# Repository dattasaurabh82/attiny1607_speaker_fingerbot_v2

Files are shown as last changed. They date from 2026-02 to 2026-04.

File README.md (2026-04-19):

# Speaker Watchdog V2 - ATtiny1607

> [!Note]
> [attiny1607_speaker_fingerbot_v1](https://github.com/dattasaurabh82/attiny1607_speaker_fingerbot)

## Overview

Monitors speaker power LED via LDR + comparator.
When LED goes OFF → wake from sleep → servo presses Fingerbot → wait for boot → sleep.

## Hardware

- PC2 (pin 19): Trigger input (comparator OUT + manual button, shared via R8 10K)
- PA5 (pin 6): Servo PWM (TCA0 WO5)
- PA6 (pin 7): Servo power gate (SI2301 P-FET control) ← **V2**
- PB2 (pin 14): TX (debug serial)
- PB3 (pin 15): RX (via JP2 jumper) ← **V2**

### Circuit info

| LDR based comparator | Microcontroller | Board Top (Combined) | Board Bottom (Combined)| 3D Render of PCB |
| --- | --- | --- | --- | --- |
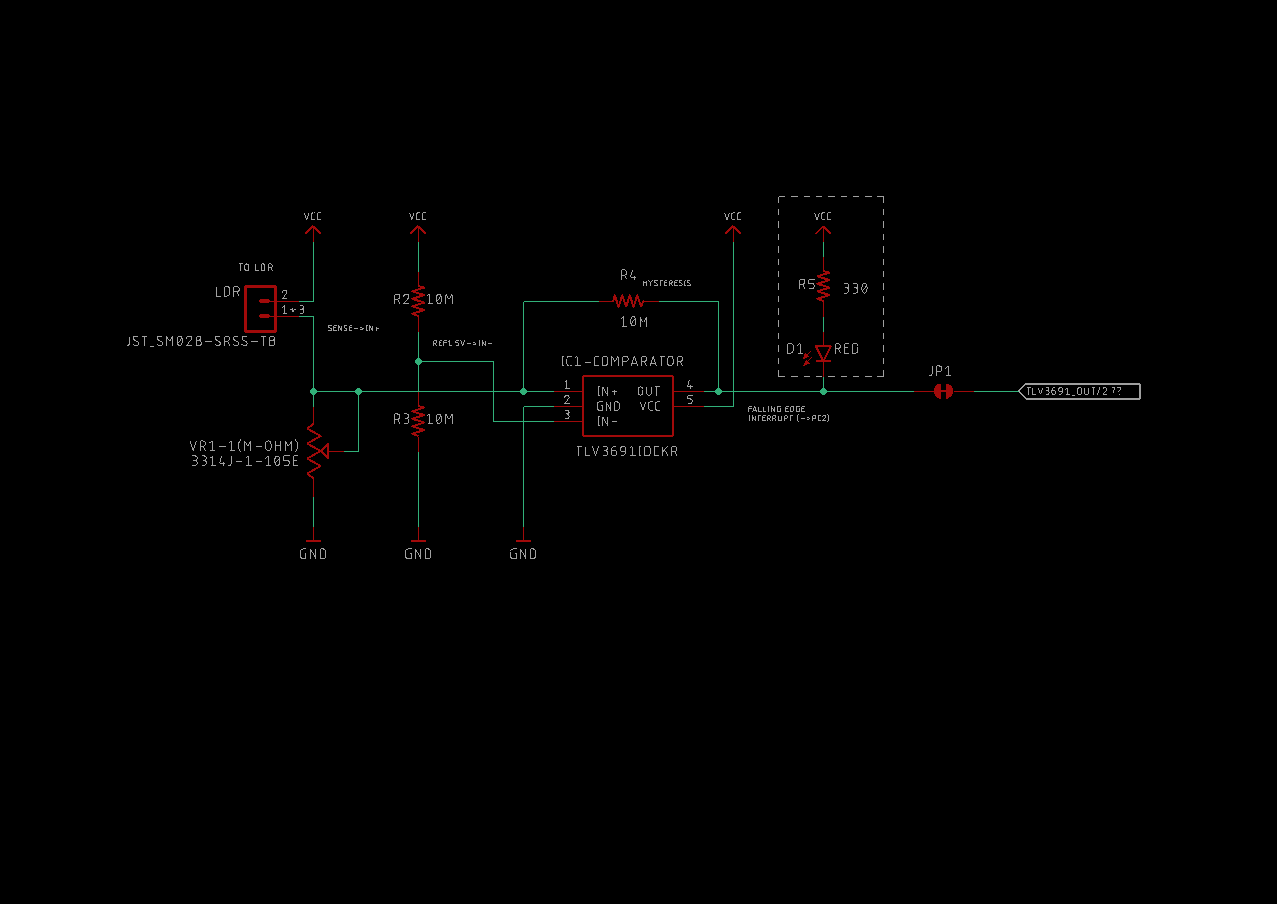
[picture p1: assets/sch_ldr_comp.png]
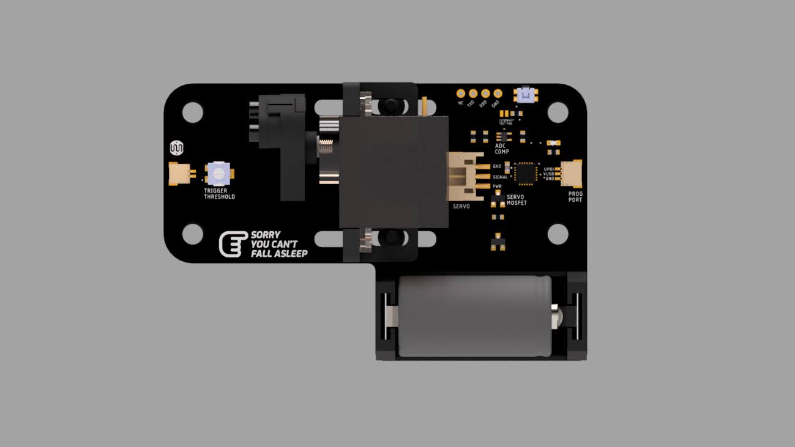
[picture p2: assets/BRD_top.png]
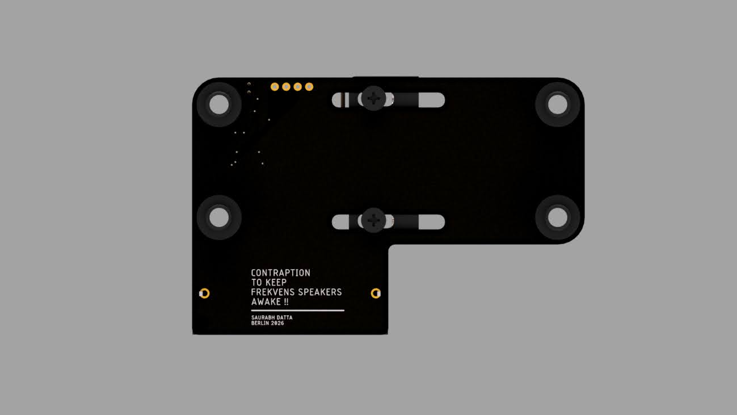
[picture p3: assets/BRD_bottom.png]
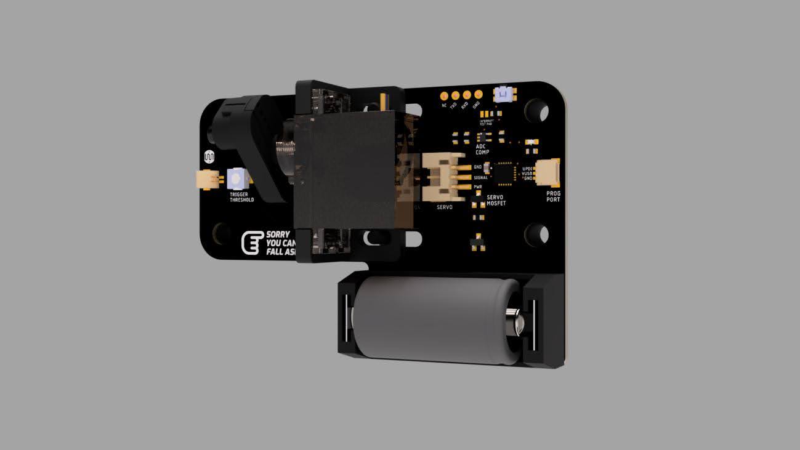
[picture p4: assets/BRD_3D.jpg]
|  |  |  |  |  |

> [!Note]
[SCHEMATIC](HW/schematic.pdf) (V-2.0)   

### What changed from V1, in V2?
> Added SI2301 P-FET to control servo power, reducing sleep current from ~2.5mA to ~300µA. Battery life improved from ~25 days to **~6 months**!

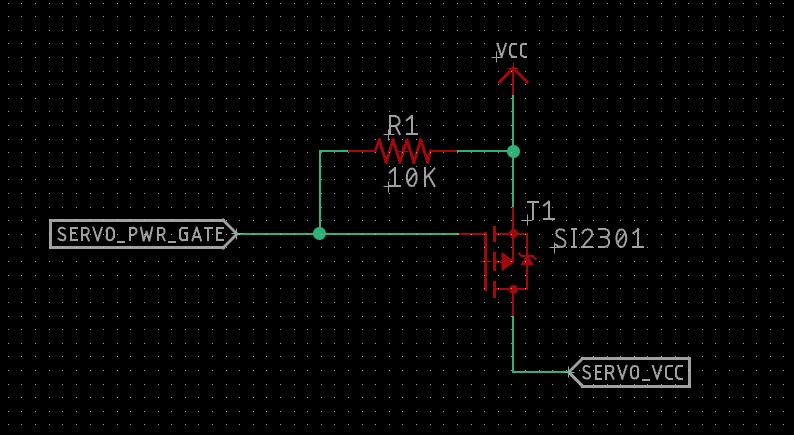
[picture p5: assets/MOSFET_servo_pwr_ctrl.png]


| MCU PA6 | Gate | Vgs | FET State | Servo |
|---|---|-----|---|---|
| HIGH (or floating) | VCC | 0V | OFF | Unpowered |
| LOW | GND | -3V | ON | Powered |

---

### Assembly (view)

<!-- ![alt text](assets/PXL_20260327_125351246.jpg) -->

<p align="center">
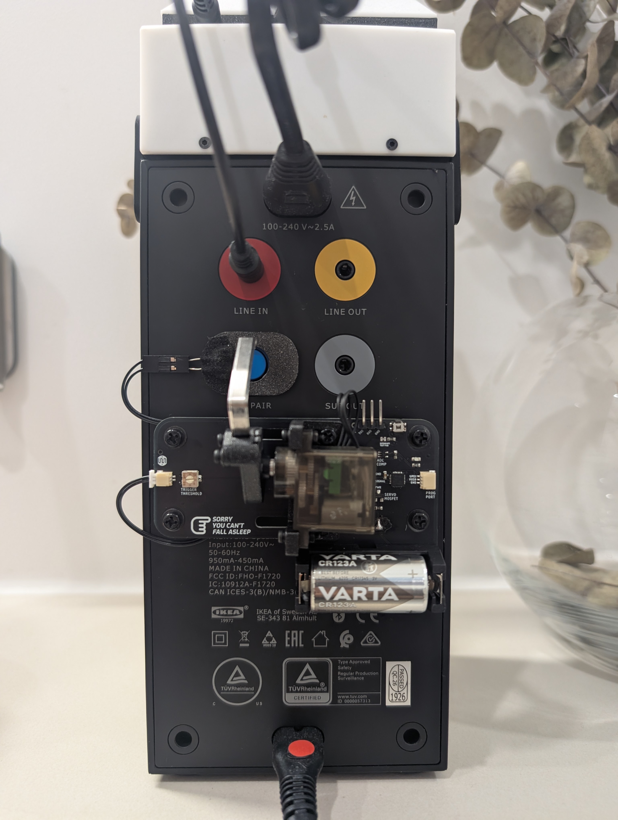
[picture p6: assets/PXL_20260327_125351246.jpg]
  
</p>

| Board bottom view | Board top view | Side view | Angled view |
| --- | --- | --- | --- |
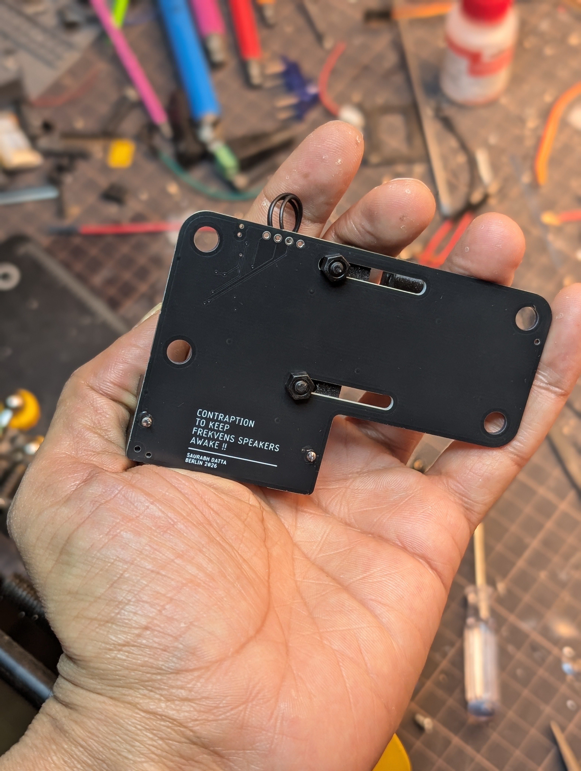
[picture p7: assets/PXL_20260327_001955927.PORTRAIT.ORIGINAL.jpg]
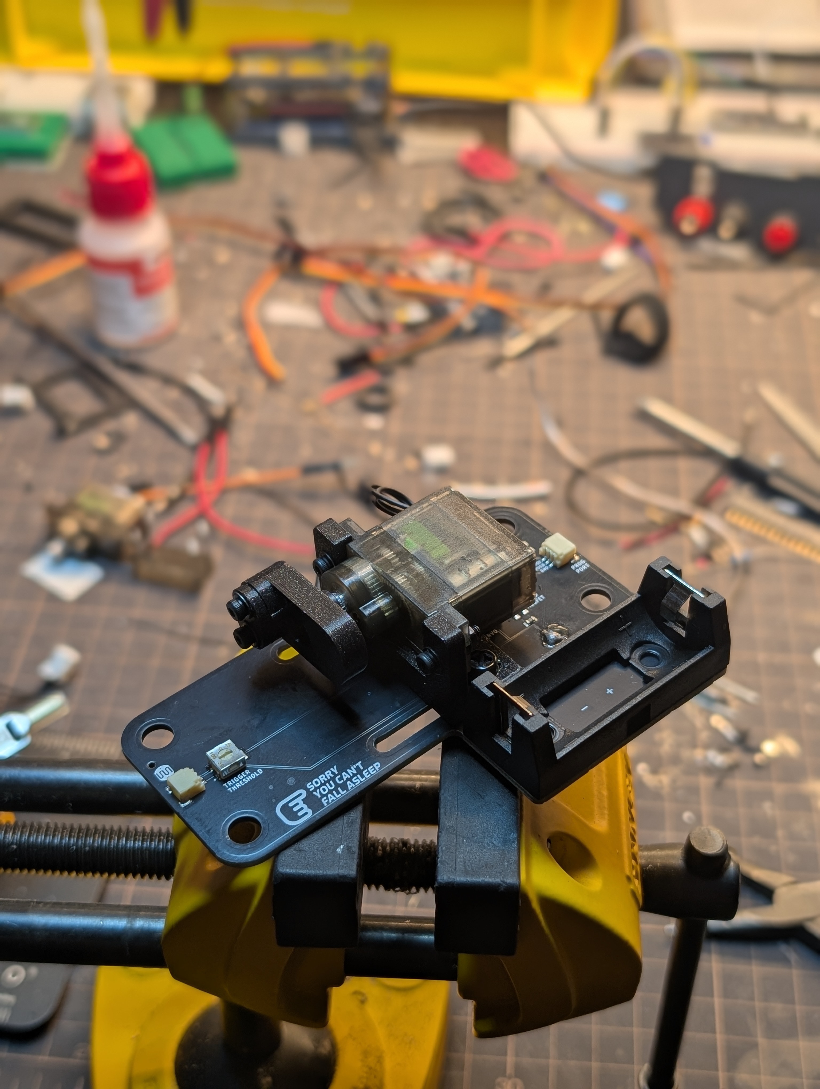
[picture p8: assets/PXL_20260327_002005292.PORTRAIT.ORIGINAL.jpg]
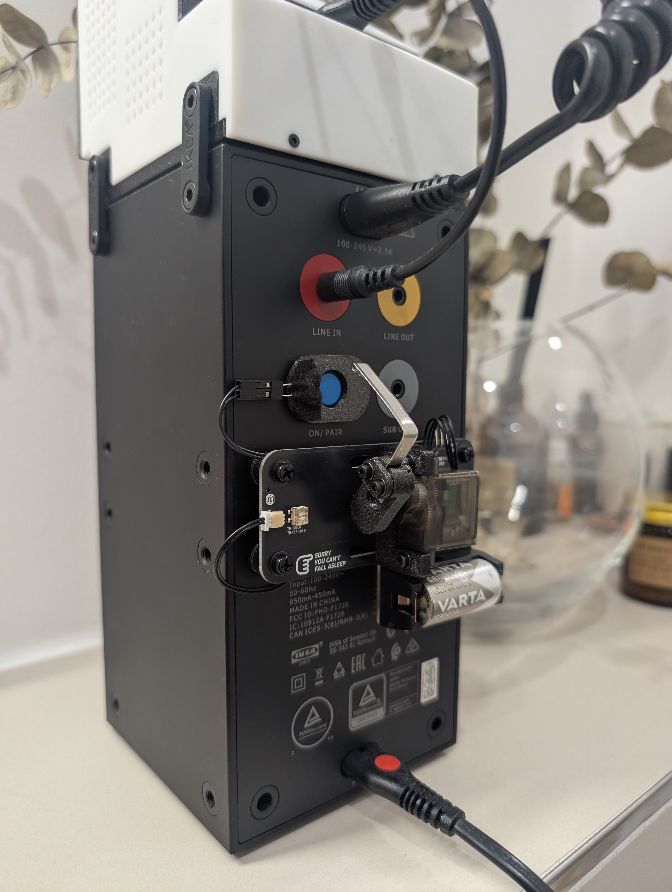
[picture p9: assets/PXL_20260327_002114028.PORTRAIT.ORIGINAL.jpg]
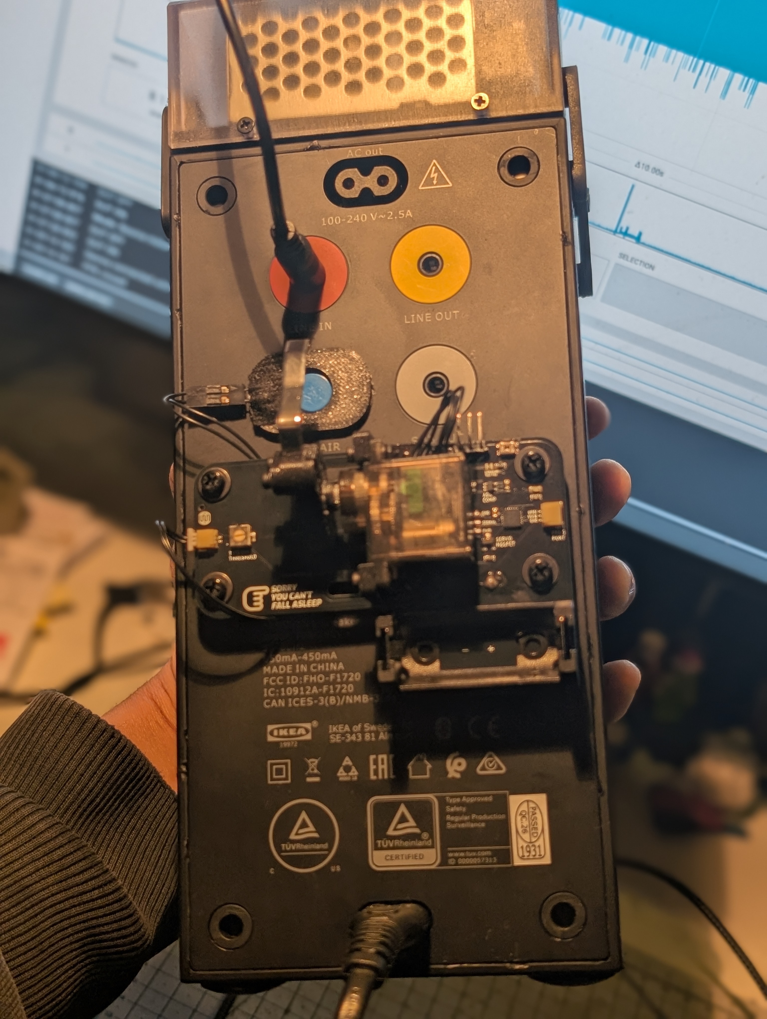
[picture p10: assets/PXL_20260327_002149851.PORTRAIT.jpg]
|  |  |  |  |

--- 

## Dependencies

- megaTinyCore: https://github.com/SpenceKonde/megaTinyCore
- Servo library: `#include <Servo_megaTinyCore.h>` (NOT `<Servo.h>`) Reason: [As Described here](https://github.com/SpenceKonde/megaTinyCore?tab=readme-ov-file#servo)

---

## Dev Setup

- IDE: Arduino IDE 2.3.8
- UPDI programmer: Could your [homebrewed one](https://github.com/SpenceKonde/AVR-Guidance/blob/master/UPDI/jtag2updi.md), but I used and followed instructions [from this one](https://learn.adafruit.com/adafruit-updi-friend?view=all)

### Compile and Upload settings:

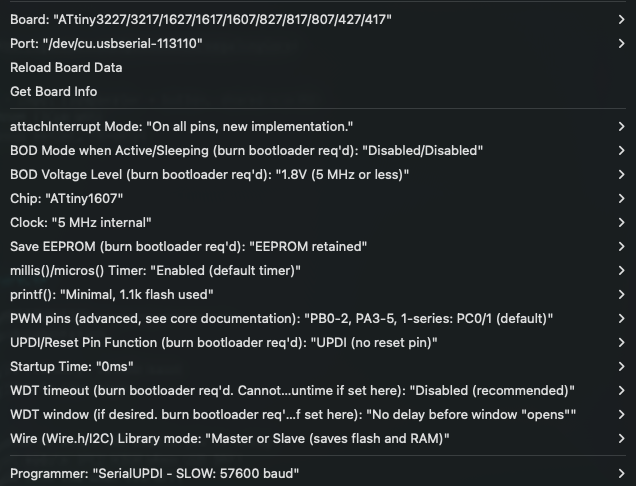
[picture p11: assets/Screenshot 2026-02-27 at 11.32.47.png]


---

## Flow

### SETUP (runs once at boot)
```
┌───────────────────────────────────────────────────────────────────┐
│  SETUP (V2)                                                       │
│  ──────────                                                       │
│  1. disableSerialPins()            // TX/RX driven LOW            │
│  2. disableUnusedPins()            // PA6 NOT included (active)   │
│  2b. disableTWI()                  // PB0/PB1 OUTPUT LOW          │
│  3. disablePeripherals()           // ADC, SPI off                │
│  4. setupTriggerPin()              // PC2 edge interrupt          │
│                                                                   │
│  5. servoPowerOn()                 // PA6=LOW → FET ON            │
│  6. delay(SERVO_STABILIZE_MS)      // Let servo settle (20ms)     │
│  7. servo.attach(PA5)                                             │
│  8. servo.write(SERVO_REST)                                       │
│  9. delay(SERVO_INIT_MS)           // Servo settles               │
│ 10. servo.detach()                                                │
│ 11. pinMode(SERVO_PIN, INPUT_PULLUP)                              │
│ 12. servoPowerOff()                // PA6=HIGH → FET OFF          │
│                                                                   │
│ 13. sei()                          // Enable global interrupts    │
│ 14. set_sleep_mode(PWR_DOWN)                                      │
│ 15. sleep_enable()                                                │
└──────────────────────────────┬────────────────────────────────────┘
                               │
                               ▼
                          ENTER LOOP
                    (servo unpowered, ~300µA sleep)
```

### MAIN LOOP
```
┌─────────────────────────────────────────────────────────────────┐
│  LOOP START                                                     │
│  ──────────                                                     │
│  - Clear pending flags                                          │
│  - sleep_cpu()                                                  │
│  - ... MCU draws ~300µA (servo is OFF via FET) ...              │
└──────────────────────────────┬──────────────────────────────────┘
                               │
               Speaker turns OFF (LED OFF)
               OR manual button pressed
               → Edge on PC2 triggers ISR
                               │
                               ▼
┌─────────────────────────────────────────────────────────────────┐
│  ISR(PORTC_PORT_vect)                                           │
│  ────────────────────                                           │
│  - flags = VPORTC.INTFLAGS                                      │
│  - PORTC.INTFLAGS = flags                                       │
│  - triggered = 1                                                │
└──────────────────────────────┬──────────────────────────────────┘
                               │
                               ▼
┌─────────────────────────────────────────────────────────────────┐
│  1. WAKE + DEBOUNCE                                             │
│     - triggered = 0                                             │
│     - [DEBUG: Serial.begin()]                                   │
│     - delay(DEBOUNCE_MS)                                        │
│     - isValidTrigger() check                                    │
│     - If FALSE → return (skip to sleep)                         │
└──────────────────────────────┬──────────────────────────────────┘
                               │
                               ▼
┌─────────────────────────────────────────────────────────────────┐
│  2. DISABLE INTERRUPT                                           │
│     - disableTriggerInterrupt()                                 │
│     - PC2 edges now ignored (prevents LED dance re-trigger)     │
└──────────────────────────────┬──────────────────────────────────┘
                               │
                               ▼
┌─────────────────────────────────────────────────────────────────┐
│  3. AWAIT BEFORE PRESS                                          │
│     - delay(SERVO_PRESS_AWAIT)    // 2000ms                     │
│     - Speaker needs time after power-off before restart works   │
└──────────────────────────────┬──────────────────────────────────┘
                               │
                               ▼
┌─────────────────────────────────────────────────────────────────┐
│  4. SERVO PRESS (V2 - with power control)                       │
│     a. servoPowerOn()             // PA6=LOW → FET ON           │
│     b. delay(SERVO_STABILIZE_MS)  // Let servo power stabilize  │
│     c. servo.attach(SERVO_PIN)                                  │
│     d. servo.write(SERVO_PRESS)   // Press position (76°)       │
│     e. delay(PRESS_HOLD_MS)       // Hold 1600ms                │
│     f. servo.write(SERVO_REST)    // Release (30°)              │
│     g. delay(PRESS_SETTLE_MS)     // Settle 1000ms              │
│     h. servo.detach()                                           │
│     i. pinMode(SERVO_PIN, INPUT_PULLUP)                         │
│     j. servoPowerOff()            // PA6=HIGH → FET OFF         │
└──────────────────────────────┬──────────────────────────────────┘
                               │
                               ▼
┌─────────────────────────────────────────────────────────────────┐
│  5. BOOT WAIT                                                   │
│     - delay(BOOT_WAIT_MS)         // 8000ms                     │
│     - Speaker boots, LED dances, interrupt disabled             │
│     - Servo already OFF (power cut by FET)                      │
└──────────────────────────────┬──────────────────────────────────┘
                               │
                               ▼
┌─────────────────────────────────────────────────────────────────┐
│  6. RE-ENABLE + CLEANUP + SLEEP                                 │
│     - enableTriggerInterrupt()                                  │
│     - clearTriggerFlags()                                       │
│     - [DEBUG: Serial cleanup]                                   │
│     - sleep_cpu()                                               │
│     - ... Back to ~300µA sleep (servo unpowered) ...            │
└─────────────────────────────────────────────────────────────────┘
```

## Edge Cases

| Case | What Happens |
|---|---|
| Power-on with speaker already OFF | No edge = no ISR. User presses button to trigger manually. |
| False trigger (noise) | Wake → debounce → re-read shows LED ON → skip action → sleep |
| LED blinks during boot | Interrupt disabled during wait, no re-triggers |
| Button pressed during wait | Interrupt disabled, ignored |
| Speaker fails to turn on | We waited 8s anyway, go to sleep. Next OFF event retries. |
| Power-on reset (MCU) | PA6 floats briefly → R1 pullup keeps FET OFF → Servo safe |
| Brown-out | Same as power-on, R1 keeps servo unpowered |
| FET fails short | Servo always powered, falls back to V1 behavior (~25 days) |
| FET fails open | Servo never powered, no button press (fails safe) |

## Configuration

```cpp
// Debug output over serial (TX-only, 115200 baud)
// Comment out for production to save power
// #define DEBUG_ENABLED

// Trigger polarity - depends on which LDR module you're using:
//   true  = off-shelf test module (PC2 HIGH when LED OFF)
//   false = our custom PCB (PC2 LOW when LED OFF)
#define INVERT_TRIGGER   false

// Servo positions in degrees - calibrate for your Fingerbot setup
#define SERVO_REST       30       // Resting position (not touching button)
#define SERVO_PRESS      76       // Press position (pushing Fingerbot button)

// Timing in milliseconds
#define DEBOUNCE_MS         50    // Wait after wake before validating trigger
#define PRESS_HOLD_MS       1600  // How long servo holds the press position
#define PRESS_SETTLE_MS     1000  // Wait for servo to return to rest before detach
#define SERVO_INIT_MS       1000  // Initial servo settle time at boot
#define BOOT_WAIT_MS        8000  // Wait for speaker boot (covers LED dance)
#define SERVO_PRESS_AWAIT   2000  // Wait before pressing (speaker needs time)
#define SERVO_STABILIZE_MS  50    // V2: Let servo power stabilize after FET ON
```

### Polarity of trigger (INTERRUPT) matters

| Module | LED ON | LED OFF | Trigger Edge |
|---|---|---|---|
| [off-shelf](https://amzn.eu/d/02HeSikt) (Test Module) | PC2 LOW | PC2 HIGH | RISING |
| Our PCB | PC2 HIGH | PC2 LOW | FALLING |

> Use `#define INVERT_TRIGGER true` for Test module.

---

## Tests

Test sketches live in `tests/` folder. Use these before running the main firmware.

[`attiny1607_speaker_led_behaviour_test.ino`](tests/attiny1607_speaker_led_behaviour_test/attiny1607_speaker_led_behaviour_test.ino)

**Purpose:** Observe and analyze the speaker LED behavior (the "dance" pattern during boot).

**Use this to:**
- Verify your LDR/comparator circuit is detecting LED state changes
- Measure the speaker's startup LED timing
- Determine the correct `BOOT_WAIT_MS` value

**Hardware:**
- PC2 (pin 19) → Comparator OUT
- PB2 (pin 14) → TX to serial adapter RX

**Usage:**
1. Upload the sketch
2. Open serial monitor at 115200 baud
3. Turn speaker ON/OFF and observe output

**Example output:**
```
LED Analyzer started
Initial: ON
[1523] OFF (was ON 1523ms)
[1842] ON (was OFF 319ms)
[2105] OFF (was ON 263ms)
[2389] ON (was OFF 284ms)
[8245] OFF (was ON 5856ms)   ← longest ON = solid period
```

**Reading the output:**
- `[elapsed_ms]` = time since sketch started
- `ON` / `OFF` = current LED state (as seen by comparator)
- `(was STATE duration)` = previous state and how long it lasted

The longest `ON` duration before a final `OFF` tells you how long the LED stays solid after the boot dance. Set `BOOT_WAIT_MS` to be longer than this.

---

## Power Consumption - V1 vs V2

### The V1 Problem

👉🏻 [Is described here](https://github.com/dattasaurabh82/attiny1607_speaker_fingerbot#oops-ma-hw-could-have-been-a-bit-better-)

### The V2 Solution

Added SI2301 P-FET to control servo power. Now the servo is completely unpowered during sleep!

| State | V1 Current | V2 Current |
| --- | --- | --- |
| Sleep | ~2.5 mA | **~300 µA** |
| Wake + servo | ~12 mA | ~12 mA |

**V2 Daily consumption:**
```
(0.3 mA × 23.9 hr) + (12 mA × 0.1 hr) = 7.17 + 1.2 ≈ 8.4 mAh/day
```

**V2 Battery life (CR123A 1500 mAh):** `1500 / 8.4 ≈ 179 days ≈ 6 months` 🎉

### V1 vs V2 Hardware Comparison

| Component | V1 | V2 |
|---|----|----|
| SI2301 P-FET (T1) | Not present | Added |
| R1 10K pullup | Not present | VCC → Gate |
| PA6 function | Unused | SERVO_PWR_GATE |
| JP2 (RX jumper) | Not present | Added |
| D1 (BAS70-05) | Present | **Must bypass for 3V operation** |
| Servo power | Always connected | Switched by FET |
| Sleep current | ~2.5 mA | **~300 µA** |
| Battery life | ~25 days | **~6 months** |

## License

[MIT](LICENSE)

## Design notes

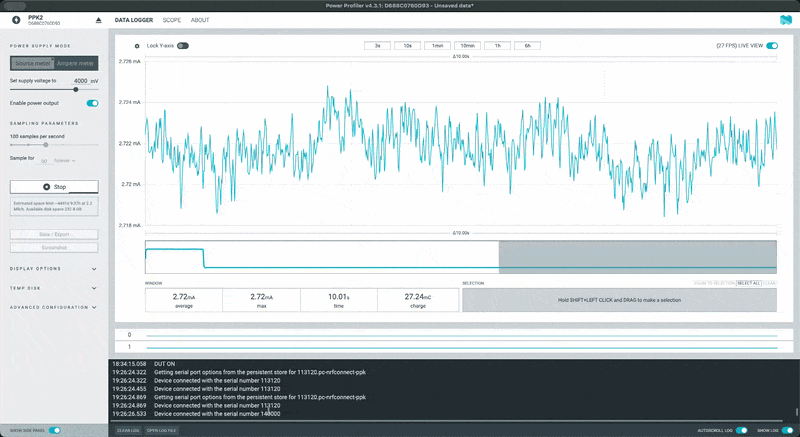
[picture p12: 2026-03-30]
assets/v1.0_power_analysis_with_servo.gif

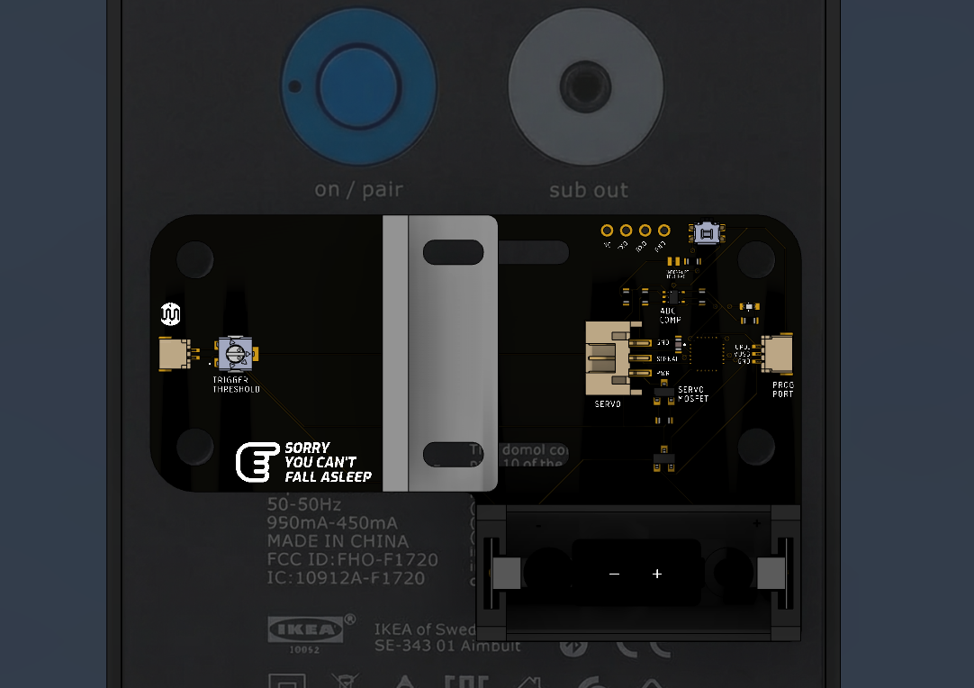
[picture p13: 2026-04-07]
assets/Screenshot 2026-04-07 at 17.49.53.png

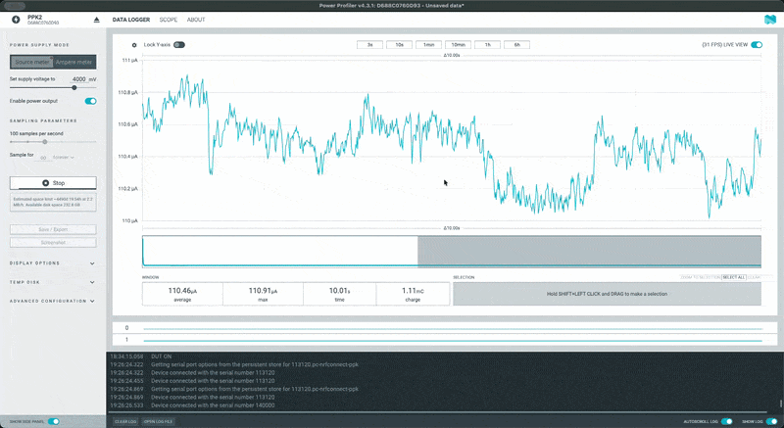
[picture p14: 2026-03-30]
assets/v1.0_power_analysis_without_servo.gif

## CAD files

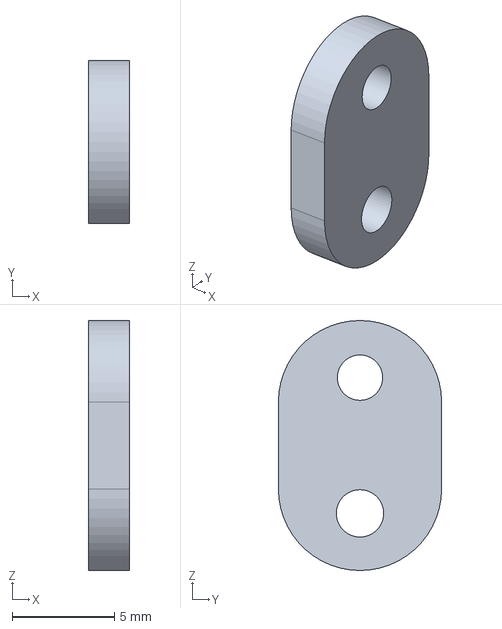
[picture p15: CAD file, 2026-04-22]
HW/ServoHornMountArmClamp.step
2.00 x 8.00 x 12.2 mm

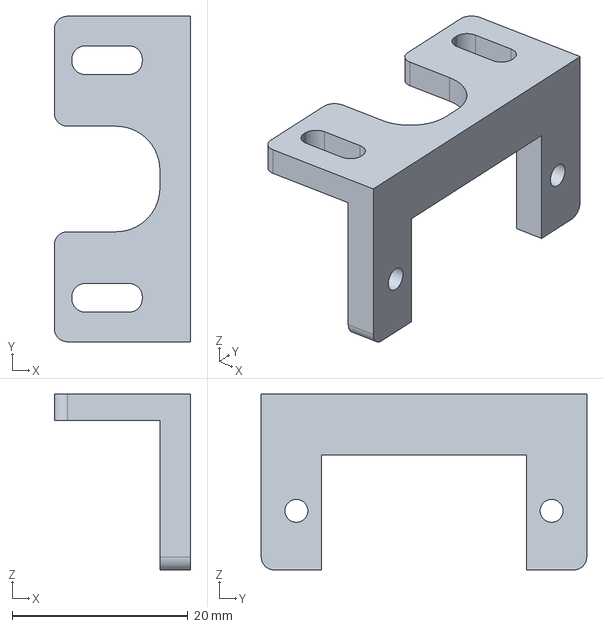
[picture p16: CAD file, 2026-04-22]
HW/V2ServoPCBMount.step
15.5 x 37.0 x 20.0 mm

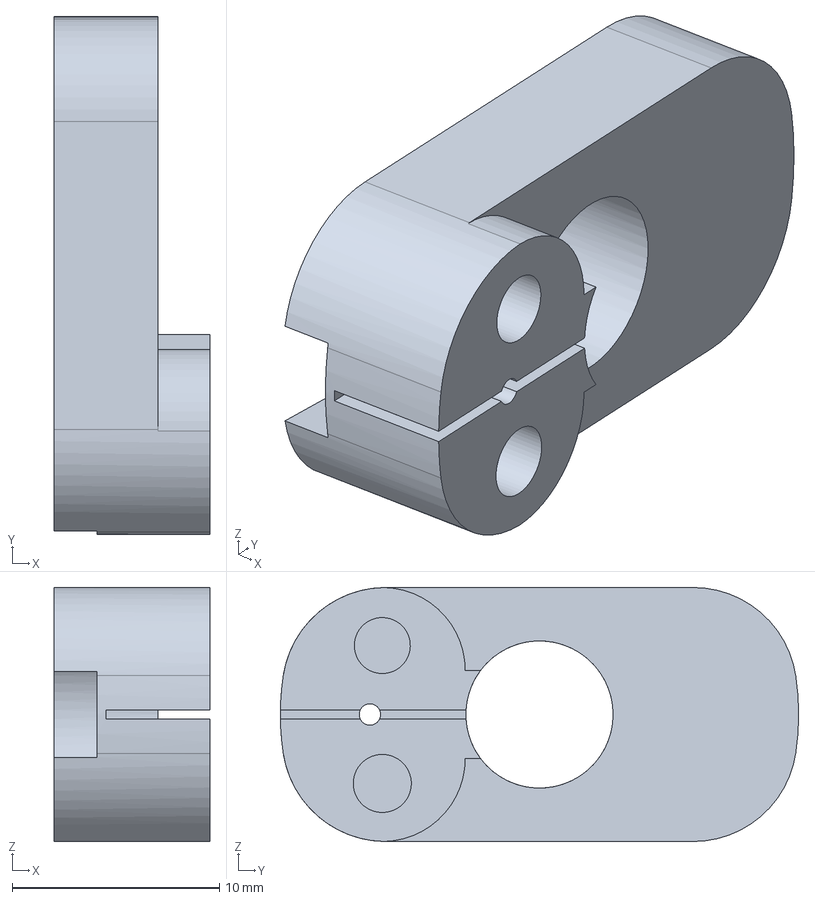
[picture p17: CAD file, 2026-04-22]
HW/ServoHornMountArm.step
7.50 x 25.0 x 12.2 mm

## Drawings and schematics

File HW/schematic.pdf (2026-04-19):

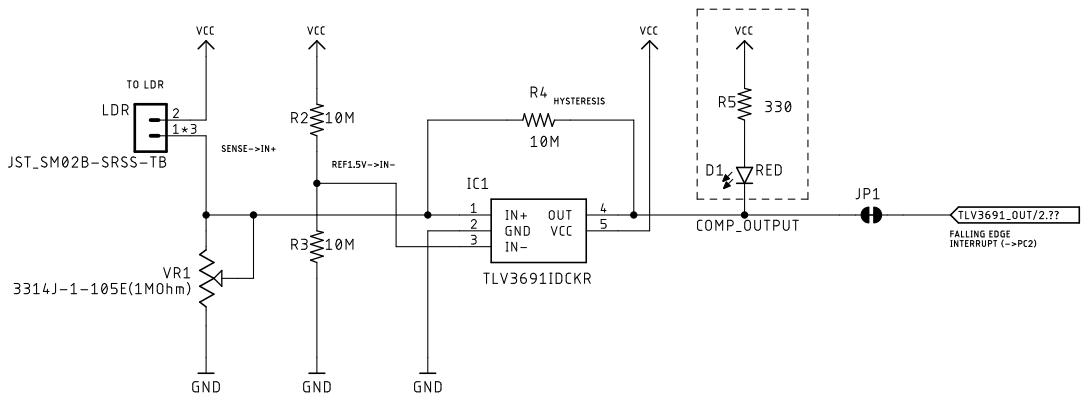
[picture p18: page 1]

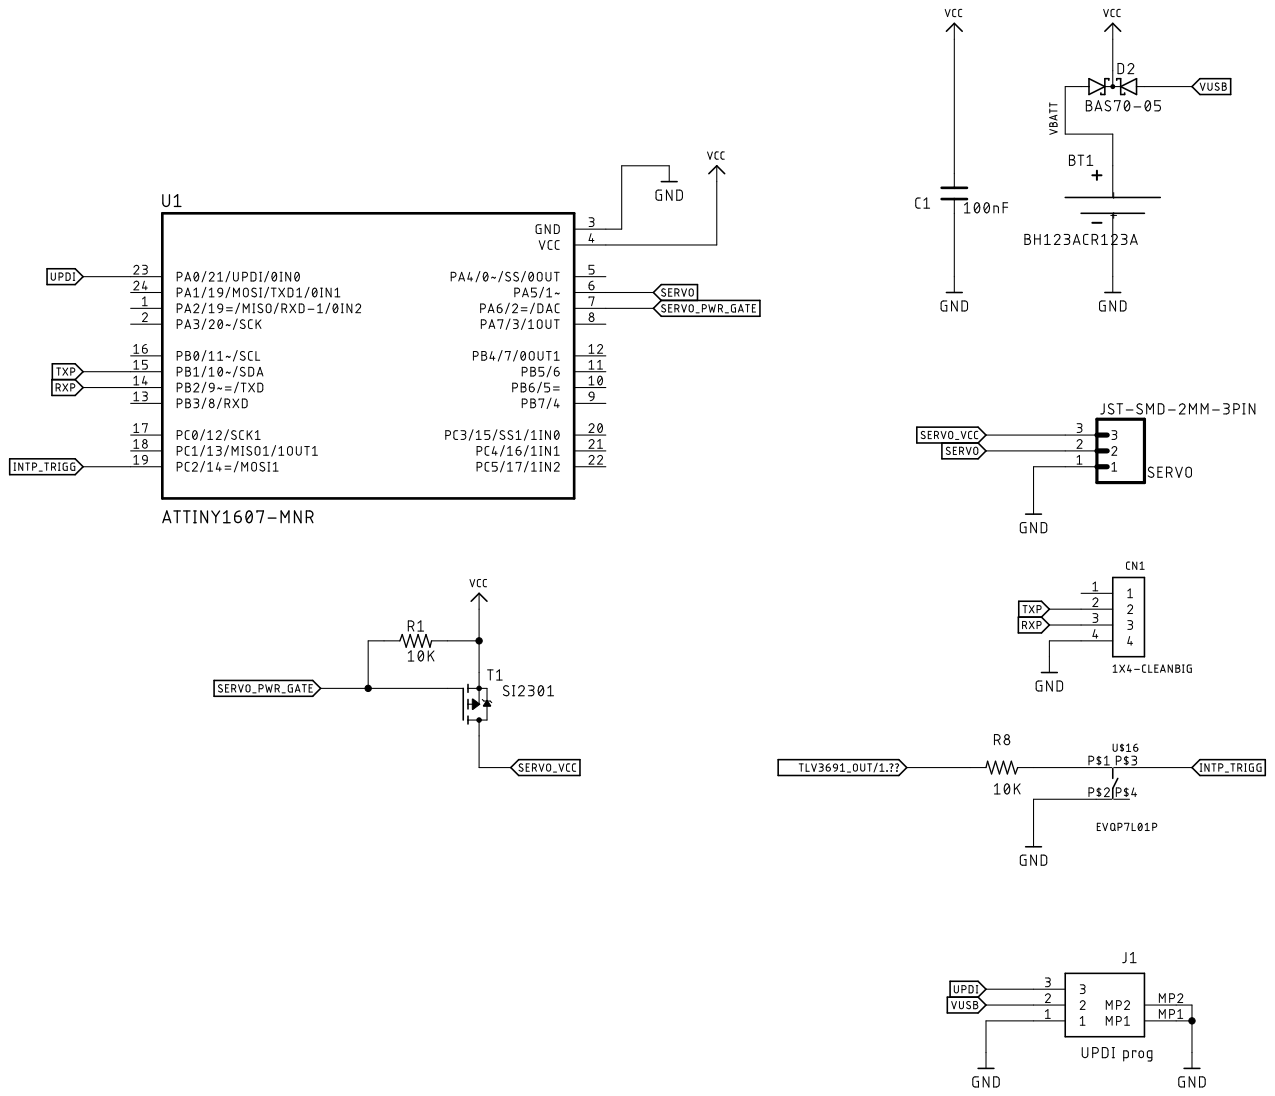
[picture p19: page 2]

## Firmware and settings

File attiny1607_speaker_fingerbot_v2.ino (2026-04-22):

/*
  Speaker Watchdog V2 - ATtiny1607
  
  Monitors speaker power LED via LDR + comparator.
  When LED goes OFF → wake → power servo → press Fingerbot → power off servo → sleep.
  
  V2 CHANGES:
    - Added SI2301 P-FET for servo power control (PA6)
    - Added RX debug header (JP2) for bidirectional serial
    - Sleep current reduced from ~2.5mA to ~100µA
    - Battery life improved from ~25 days to ~14 months
  
  Target: ATtiny1607
  Core: megaTinyCore (https://github.com/SpenceKonde/megaTinyCore)
  
  Hardware:
    PC2 (pin 19) - Trigger input (comparator + button, shared via R8)
    PA5 (pin 6)  - Servo PWM (TCA0 WO5)
    PA6 (pin 7)  - Servo power gate (SI2301 P-FET control)
    PB2 (pin 14) - TX (debug serial)
    PB3 (pin 15) - RX (debug serial, active via JP2)
  
  SI2301 P-FET Wiring:
    Gate   (pin 1) ← PA6 + R1 10K pullup to VCC
    Source (pin 2) ← VCC (3V)
    Drain  (pin 3) → Servo VCC (red wire)
  
  Logic:
    PA6 HIGH (or floating) → Gate at VCC → Vgs=0V  → FET OFF → Servo unpowered
    PA6 LOW               → Gate at GND → Vgs=-3V → FET ON  → Servo powered
  
  Author: Saurabh Datta
  Date: April 2026
  License: MIT
*/

#include <avr/sleep.h>
#include <Servo_megaTinyCore.h>

// ==================== CONFIGURATION ====================
// See README.md for full documentation

// Debug output over serial (115200 baud)
// V2: Both TX (PB2) and RX (PB3) available via headers
// Comment out for production to save power
// #define DEBUG_ENABLED

// Trigger polarity - depends on which LDR module you're using:
//   true  = off-shelf test module (PC2 HIGH when LED OFF)
//   false = our custom PCB (PC2 LOW when LED OFF)
#define INVERT_TRIGGER false

// Servo positions in degrees - calibrate for your Fingerbot setup
#define SERVO_REST 45   // Resting position (not touching button)
#define SERVO_PRESS 96  // Press position (pushing Fingerbot button)

// Timing in milliseconds
#define DEBOUNCE_MS 50          // Wait after wake before validating trigger
#define PRESS_HOLD_MS 1700      // How long servo holds the press position OLD 1600
#define PRESS_SETTLE_MS 1000    // Wait for servo to return to rest before detach
#define SERVO_INIT_MS 1000      // Initial servo settle time at boot
#define BOOT_WAIT_MS 8000       // Wait for speaker boot (covers LED dance)
#define SERVO_PRESS_AWAIT 2000  // Wait before pressing (speaker needs time after power-off)
#define SERVO_STABILIZE_MS 100  // Let servo power stabilize after FET turns ON

// ==================== PIN DEFINITIONS ====================

#define TRIGGER_PIN PIN_PC2
#define SERVO_PIN PIN_PA5
#define SERVO_PWR_PIN PIN_PA6  // V2: Controls SI2301 P-FET gate

// ==================== GLOBALS ====================

Servo servo;
volatile byte triggered = 0;
bool serialActive = false;  // Track if Serial was started

// ==================== ISR ====================

ISR(PORTC_PORT_vect) {
  byte flags = VPORTC.INTFLAGS;
  PORTC.INTFLAGS = flags;
  triggered = 1;
}

// ==================== SERVO POWER CONTROL (V2) ====================

void servoPowerOn() {
  // PA6 LOW → Gate LOW → Vgs = -3V → P-FET conducts → Servo powered
  pinMode(SERVO_PWR_PIN, OUTPUT);
  digitalWrite(SERVO_PWR_PIN, LOW);
}

void servoPowerOff() {
  // PA6 HIGH → Gate HIGH → Vgs = 0V → P-FET off → Servo unpowered
  // Then set to INPUT_PULLUP as belt-and-suspenders (R1 also pulls high)
  digitalWrite(SERVO_PWR_PIN, HIGH);
  pinMode(SERVO_PWR_PIN, INPUT_PULLUP);
}

// ==================== HARDWARE HELPERS ====================

void disableUnusedPins() {
  // PORTA: PA0=UPDI(skip), PA5=SERVO(skip), PA6=SERVO_PWR(skip), rest unused
  PORTA.PIN1CTRL = PORT_PULLUPEN_bm;
  PORTA.PIN2CTRL = PORT_PULLUPEN_bm;
  PORTA.PIN3CTRL = PORT_PULLUPEN_bm;
  PORTA.PIN4CTRL = PORT_PULLUPEN_bm;
  // PA6 is now SERVO_PWR_PIN - NOT set to INPUT_PULLUP here (handled by servoPowerOff)
  PORTA.PIN7CTRL = PORT_PULLUPEN_bm;

  // PORTB: PB0/PB1=TWI (handled by disableTWI), PB2=TX, PB3=RX (handled by disableSerialPins), rest unused
  PORTB.PIN4CTRL = PORT_PULLUPEN_bm;
  PORTB.PIN5CTRL = PORT_PULLUPEN_bm;

  // PORTC: PC2=TRIGGER(skip), rest unused
  PORTC.PIN0CTRL = PORT_PULLUPEN_bm;
  PORTC.PIN1CTRL = PORT_PULLUPEN_bm;
  PORTC.PIN3CTRL = PORT_PULLUPEN_bm;
  PORTC.PIN4CTRL = PORT_PULLUPEN_bm;
  PORTC.PIN5CTRL = PORT_PULLUPEN_bm;
}

void disableSerialPins() {
  PORTB.DIRSET = PIN2_bm;
  PORTB.DIRSET = PIN3_bm;
  cli();
  PORTB.OUT &= ~PIN2_bm;
  PORTB.OUT &= ~PIN3_bm;
  sei();
}

void disableTWI() {
  // Set TWI pins (PB0, PB1) as OUTPUT LOW for lowest power
  PORTB.DIRSET = PIN0_bm;
  PORTB.DIRSET = PIN1_bm;
  cli();
  PORTB.OUT &= ~PIN0_bm;
  PORTB.OUT &= ~PIN1_bm;
  sei();
}

void disablePeripherals() {
  ADC0.CTRLA &= ~ADC_ENABLE_bm;
  SPI0.CTRLA &= ~SPI_ENABLE_bm;
}

void setupTriggerPin() {
#if INVERT_TRIGGER
  PORTC.PIN2CTRL = PORT_ISC_RISING_gc;
#else
  PORTC.PIN2CTRL = PORT_ISC_FALLING_gc;
#endif
}

void disableTriggerInterrupt() {
  PORTC.PIN2CTRL &= ~PORT_ISC_gm;
}

void enableTriggerInterrupt() {
#if INVERT_TRIGGER
  PORTC.PIN2CTRL = PORT_ISC_RISING_gc;
#else
  PORTC.PIN2CTRL = PORT_ISC_FALLING_gc;
#endif
}

void clearTriggerFlags() {
  PORTC.INTFLAGS = PIN2_bm;
  triggered = 0;
}

// ==================== TRIGGER VALIDATION ====================

bool isValidTrigger() {
  bool pinHigh = (PORTC.IN & PIN2_bm);

#if INVERT_TRIGGER
  return pinHigh;
#else
  return !pinHigh;
#endif
}

// ==================== SERVO ====================

void servoPress() {
#ifdef DEBUG_ENABLED
  if (serialActive) {
    Serial.println(F("Servo: power ON (FET)"));
  }
#endif

  // V2: Power up servo via FET
  servoPowerOn();

#ifdef DEBUG_ENABLED
  if (serialActive) {
    Serial.print(F("Servo: stabilize "));
    Serial.print(SERVO_STABILIZE_MS);
    Serial.println(F("ms"));
  }
#endif

  // Let servo electronics stabilize after power-up
  delay(SERVO_STABILIZE_MS);

#ifdef DEBUG_ENABLED
  if (serialActive) {
    Serial.print(F("Servo: attach, move to PRESS ("));
    Serial.print(SERVO_PRESS);
    Serial.println(F(" deg)"));
  }
#endif

  servo.attach(SERVO_PIN);
  servo.write(SERVO_PRESS);

#ifdef DEBUG_ENABLED
  if (serialActive) {
    Serial.print(F("Servo: hold "));
    Serial.print(PRESS_HOLD_MS);
    Serial.println(F("ms"));
  }
#endif

  delay(PRESS_HOLD_MS);

#ifdef DEBUG_ENABLED
  if (serialActive) {
    Serial.print(F("Servo: move to REST ("));
    Serial.print(SERVO_REST);
    Serial.println(F(" deg)"));
  }
#endif

  servo.write(SERVO_REST);

#ifdef DEBUG_ENABLED
  if (serialActive) {
    Serial.print(F("Servo: settle "));
    Serial.print(PRESS_SETTLE_MS);
    Serial.println(F("ms"));
  }
#endif

  delay(PRESS_SETTLE_MS);

#ifdef DEBUG_ENABLED
  if (serialActive) {
    Serial.println(F("Servo: detach"));
  }
#endif

  servo.detach();
  pinMode(SERVO_PIN, INPUT_PULLUP);

#ifdef DEBUG_ENABLED
  if (serialActive) {
    Serial.println(F("Servo: power OFF (FET)"));
  }
#endif

  // V2: Cut servo power via FET
  servoPowerOff();
}

// ==================== MAIN HANDLER ====================

void handleWakeUp() {
#ifdef DEBUG_ENABLED
  Serial.begin(115200);
  serialActive = true;
  delay(10);
  Serial.println(F(""));
  Serial.println(F("=== WAKE (V2) ==="));
#endif

// 2. Debounce
#ifdef DEBUG_ENABLED
  if (serialActive) {
    Serial.print(F("Debounce: "));
    Serial.print(DEBOUNCE_MS);
    Serial.println(F("ms"));
  }
#endif

  delay(DEBOUNCE_MS);

#ifdef DEBUG_ENABLED
  if (serialActive) {
    bool pinState = (PORTC.IN & PIN2_bm);
    Serial.print(F("PC2: "));
    Serial.println(pinState ? "HIGH" : "LOW");
  }
#endif

  if (!isValidTrigger()) {
#ifdef DEBUG_ENABLED
    if (serialActive) {
      Serial.println(F("FALSE TRIGGER"));
    }
#endif
    return;
  }

#ifdef DEBUG_ENABLED
  if (serialActive) {
    Serial.println(F("VALID TRIGGER"));
    Serial.println(F("Disable PC2 interrupt"));
  }
#endif

  // 3. Disable interrupt
  disableTriggerInterrupt();

// ** NOTE: Add some await before Servo press
// Or else if we press immediately after the speaker gets OFF (speaker LED OFF),
// then pressing it, to turn it ON doesn't work
#ifdef DEBUG_ENABLED
  if (serialActive) {
    Serial.print(F("Waiting for: "));
    Serial.print(SERVO_PRESS_AWAIT);
    Serial.println(F("ms before pressing servo"));
  }
#endif

  delay(SERVO_PRESS_AWAIT);
  //============================= //

  // 4. Servo press (V2: includes power on/off via FET)
  servoPress();

// 5. Fixed wait
#ifdef DEBUG_ENABLED
  if (serialActive) {
    Serial.print(F("Boot wait: "));
    Serial.print(BOOT_WAIT_MS);
    Serial.println(F("ms"));
  }
#endif

  delay(BOOT_WAIT_MS);

#ifdef DEBUG_ENABLED
  if (serialActive) {
    Serial.println(F("Boot wait done"));
  }
#endif
}

// ==================== SETUP ====================

void setup() {
  // 1. Disable serial pins
  disableSerialPins();

  // 2. Disable unused pins (PA6 NOT included - it's SERVO_PWR_PIN now)
  disableUnusedPins();

  // 2b. Disable TWI pins (PB0, PB1 as OUTPUT LOW)
  disableTWI();

  // 3-4. Disable peripherals
  disablePeripherals();

  // 5. Setup trigger pin
  setupTriggerPin();

  // 6. V2: Power up servo via FET for initial positioning
  servoPowerOn();
  delay(SERVO_STABILIZE_MS);

  // 7-10. Initialize servo to rest, then detach
  servo.attach(SERVO_PIN);
  servo.write(SERVO_REST);
  delay(SERVO_INIT_MS);
  servo.detach();
  pinMode(SERVO_PIN, INPUT_PULLUP);

  // 11. V2: Cut servo power for low-power sleep
  servoPowerOff();

  // 12. Enable interrupts
  sei();

  // 13-14. Sleep mode setup
  set_sleep_mode(SLEEP_MODE_PWR_DOWN);
  sleep_enable();
}

// ==================== LOOP ====================

void loop() {
  // 1. Check if triggered
  if (triggered) {
    triggered = 0;
    handleWakeUp();
  }

  // 6. Re-enable interrupt + cleanup + sleep
  enableTriggerInterrupt();
  clearTriggerFlags();

#ifdef DEBUG_ENABLED
  if (serialActive) {
    Serial.println(F("Enable PC2 interrupt"));
    Serial.println(F("Clear flags"));
    Serial.println(F("Sleep... (servo unpowered via FET)"));
    Serial.flush();
    Serial.end();
    disableSerialPins();
    serialActive = false;
  }
#endif

  // Sleep (V2: ~100µA with servo power cut by FET)
  sleep_cpu();
}

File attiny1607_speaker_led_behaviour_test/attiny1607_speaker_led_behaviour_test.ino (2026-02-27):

/*
  Simple test sketch to observe speaker LED behavior.
  Target: ATtiny1607
  Hardware:
    PC2 (pin 19) - Trigger input (comparator OUT)
    PB2 (pin 14) - TX to serial adapter RX
  Serial: 115200 baud (TX only)
  Format: [elapsed_ms] STATE duration_ms
*/

#define TRIGGER_PIN PIN_PC2
#define POLL_INTERVAL 20

bool lastState = false;
unsigned long stateStartTime = 0;
unsigned long runStartTime = 0;

void setup() {
  Serial.begin(115200);
  delay(100);

  pinMode(TRIGGER_PIN, INPUT);

  runStartTime = millis();
  stateStartTime = millis();
  lastState = (PORTC.IN & PIN2_bm);

  Serial.println(F("LED Analyzer started"));
  Serial.print(F("Initial: "));
  Serial.println(lastState ? "OFF" : "ON");
}

void loop() {
  bool currentState = (PORTC.IN & PIN2_bm);

  if (currentState != lastState) {
    unsigned long duration = millis() - stateStartTime;
    unsigned long elapsed = millis() - runStartTime;

    Serial.print(F("["));
    Serial.print(elapsed);
    Serial.print(F("] "));
    Serial.print(currentState ? "OFF " : "ON");
    Serial.print(F(" (was "));
    Serial.print(lastState ? "OFF " : "ON");
    Serial.print(duration);
    Serial.println(F("ms)"));

    lastState = currentState;
    stateStartTime = millis();
  }

  delay(POLL_INTERVAL);
}
